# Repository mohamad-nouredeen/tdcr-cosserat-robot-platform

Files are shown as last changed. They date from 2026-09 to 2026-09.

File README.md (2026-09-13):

# Tendon-Driven Continuum Robot Platform

A single-segment tendon-driven continuum robot developed during my
master's thesis internship at ISIR, Sorbonne Université, as part of the
Master's Degree in Mechatronic Engineering at Politecnico di Torino.

This project integrates static and dynamic Cosserat-rod modeling,
mechanical design, DYNAMIXEL tendon actuation, electronics, and
preliminary experimental evaluation of a physical TDCR prototype.

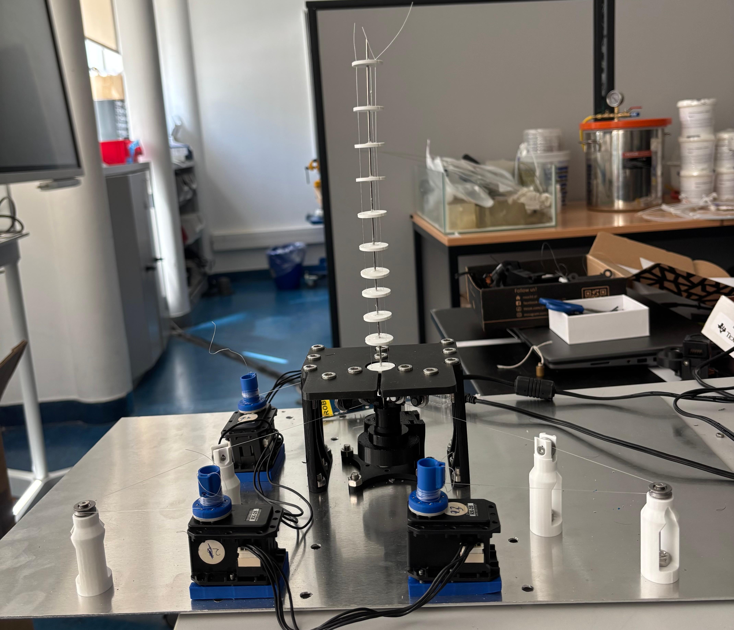
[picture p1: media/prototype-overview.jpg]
Complete tendon-driven continuum robot prototype


## Robot Demonstration

Physical prototype during tendon actuation.

https://github.com/user-attachments/assets/3df236bc-30ad-41d0-9584-1410d35f72d1

## Prototype

The developed robot consists of:

- A 250 mm hollow Nitinol backbone
- Eleven spacer disks
- Three nylon tendons arranged approximately 120° apart
- Three DYNAMIXEL RX-28 actuators
- Motor-driven tendon spools with a nominal effective radius of 2.5 mm
- A MATLAB R2025a actuation interface using the DYNAMIXEL SDK

The mathematical models use a nominal symmetric tendon-routing radius
of 6 mm. The supplied manufactured disk STL differs from this nominal
model geometry; the measured mesh geometry and related reproducibility
notes are documented in
[`mechanical/README.md`](mechanical/README.md).

## Modeling Approach

### Static Cosserat-Rod Models

Two static Cosserat-rod formulations are included.

**Newtonian formulation**

The Newtonian model is based on distributed force and moment equilibrium.
The spatial equations are integrated numerically using `ode45`, while a
shooting method and `fsolve` are used to satisfy the boundary conditions.

**Lagrangian formulation**

The Lagrangian model represents the rod strains through a finite
strain-basis approximation and determines the equilibrium configuration
using an energy-based formulation and Newton-Raphson iteration.

For the loading cases examined in the thesis, the two formulations
produced practically identical predicted tip positions.

The corresponding implementations are available in
[`modeling/`](modeling/).

### Displacement-to-Tension Iteration

The static Cosserat formulations use tendon tension as a model input,
while the physical actuation system is commanded using nominal tendon
pull.

An outer PD-based numerical iteration was therefore implemented to
adjust tendon tension until the Newtonian model reproduces a prescribed
tendon shortening.

This procedure is an offline numerical algorithm and is separate from
the physical DYNAMIXEL motor controller.

### Dynamic Model

The dynamic Cosserat-rod implementation investigates the transient
backbone response under time-dependent tendon tensions.

The formulation includes backbone inertia, internal damping, gravity,
drag, and time-dependent tendon loading. Temporal integration is based
on an implicit BDF-alpha formulation combined with spatial integration
of the rod equations.

The dynamic results contained in this repository are numerical
predictions and were not experimentally validated during the project.

## Actuation and Electronics

Three ROBOTIS DYNAMIXEL RX-28 actuators are used, with one actuator
assigned to each tendon.

The implemented communication architecture is:

```text
Computer / MATLAB R2025a
        |
       USB
        |
   ROBOTIS U2D2
        |
      RS-485
        |
   U2D2 Power Hub
        |
   RS-485 + Power
        |
      RX-28 ID 1
        |
    Daisy chain
        |
      RX-28 ID 2
        |
    Daisy chain
        |
      RX-28 ID 3
```

The MATLAB actuation interface converts prescribed nominal tendon pulls
into DYNAMIXEL Goal Position commands.

The motor shaft positions are internally regulated by the RX-28
controllers. However, actual tendon displacement, tendon tension,
backbone shape, and robot tip position are not directly measured.

The implementation is available in
[`actuation/`](actuation/), while the hardware architecture is
documented in [`electronics/`](electronics/).

## Preliminary Experimental Evaluation

The physical robot was compared with the Newtonian static model using
one unloaded condition and six single-active-tendon tests.

The nominal tendon-pull commands were 5 mm and 10 mm.

| Metric | Value |
|---|---:|
| Mean absolute vertical-position error | 11.54 mm |
| Root-mean-square vertical-position error | 14.01 mm |
| Maximum absolute vertical-position error | 21.08 mm |
| Mean relative error | Approximately 6.51% |

The model reproduced the principal relationship between increasing
nominal tendon pull and increasing backbone deformation.

However, the physical robot bent less than predicted by the static model,
particularly for the 10 mm commands.

Possible sources of discrepancy include tendon friction, slack,
elongation or permanent deformation, spool-winding effects,
manufacturing asymmetries, mechanical tolerances, and uncertainty
between commanded and actual tendon displacement.

The complete experimental comparison is documented in
[`experiments/`](experiments/).

## Repository Structure

| Location | Contents |
|---|---|
| [`modeling/`](modeling/) | Newtonian and Lagrangian static models, dynamic model, displacement-to-tension iteration, comparison scripts, and supporting MATLAB functions |
| [`actuation/`](actuation/) | MATLAB interface for commanding the DYNAMIXEL RX-28 actuators |
| [`mechanical/`](mechanical/) | Mechanical STL files and geometry/reproducibility documentation |
| [`electronics/`](electronics/) | Communication, power, U2D2, Power Hub, and actuator documentation |
| [`experiments/`](experiments/) | Experimental comparison figures, results, metrics, and discussion |
| [`docs/`](docs/) | Master's thesis and thesis documentation |
| [`media/`](media/) | Prototype photographs and robot demonstration video |
| [`CITATION.cff`](CITATION.cff) | Citation metadata for this repository |
| [`THIRD_PARTY_NOTICES.md`](THIRD_PARTY_NOTICES.md) | Attribution and third-party software information |
| [`LICENSE`](LICENSE) | GNU General Public License v3.0 |

## Master's Thesis

The complete thesis associated with this repository is:

**Static and Dynamic Cosserat-Rod Modeling of a Single-Segment
Tendon-Driven Continuum Robot**

**Author:** Mohamad Nour Edeen  
**Master's Degree:** Mechatronic Engineering  
**University:** Politecnico di Torino  
**Research host:** ISIR, Sorbonne Université

[Read the thesis PDF](docs/Master_Thesis_Mohamad_Nouredeen.pdf)

Additional thesis information is available in
[`docs/README.md`](docs/README.md).

## Software Requirements

The thesis implementations were developed using **MATLAB R2025a**.

The static Newtonian and dynamic implementations use `fsolve` from the
MATLAB Optimization Toolbox.

The physical actuation interface additionally requires the
ROBOTIS DYNAMIXEL SDK and compatible DYNAMIXEL hardware.

The repository version has not yet been independently reproduced on a
separate computer. Users should therefore verify dependencies,
environment configuration, and hardware settings before execution.

## Attribution

Parts of the static Newtonian and Lagrangian Cosserat-rod
implementations are adapted from the open-source TIMClab-CAMI project
associated with:

Matthias Tummers et al. (2023),  
**"Cosserat Rod Modeling of Continuum Robots from Newtonian and
Lagrangian Perspectives,"**  
*IEEE Transactions on Robotics*.

DOI:  
https://doi.org/10.1109/TRO.2023.3238171

Original implementation:  
https://github.com/TIMClab-CAMI/Cosserat-Rod-Modeling-of-Tendon-Actuated-Continuum-Robots

The project-specific adaptations include robot geometry and material
parameters, tendon-routing configuration, additional numerical outputs,
comparison procedures, and the displacement-to-tension iteration.

Detailed attribution information is provided in
[`THIRD_PARTY_NOTICES.md`](THIRD_PARTY_NOTICES.md).

The repository includes the applicable GPL-3.0 license text in
[`LICENSE`](LICENSE).

## Citation

If you use material from this repository, please cite the repository
using the metadata provided in:

[`CITATION.cff`](CITATION.cff)

Users of the adapted static Cosserat-rod implementation should also cite
the original Tummers et al. publication listed above.

## Author

**Mohamad Nour Edeen**

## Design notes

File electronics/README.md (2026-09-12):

# Electronics and Actuation Hardware

This folder documents the electronic, communication, and actuator architecture implemented for the tendon-driven continuum robot platform.

The system uses three ROBOTIS DYNAMIXEL RX-28 actuators, one for each tendon. MATLAB R2025a communicates with the actuators through a ROBOTIS U2D2 interface and a U2D2 Power Hub.

## System Architecture

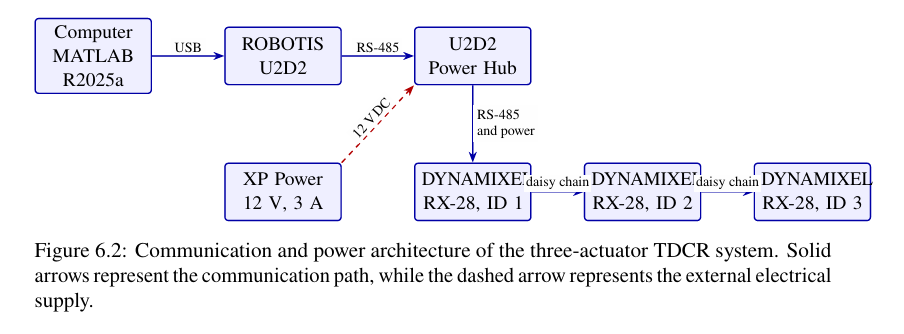
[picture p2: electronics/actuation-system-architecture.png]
Actuation system architecture


The implemented communication and power chain is:

```text
Computer / MATLAB R2025a
        |
       USB
        |
   ROBOTIS U2D2
        |
      RS-485
        |
   U2D2 Power Hub
        |
   RS-485 + Power
        |
 DYNAMIXEL RX-28, ID 1
        |
    Daisy chain
        |
 DYNAMIXEL RX-28, ID 2
        |
    Daisy chain
        |
 DYNAMIXEL RX-28, ID 3
 
 An external 12 V, 3 A power supply is connected to the U2D2 Power Hub, which distributes power and communication to the three actuators.

The motor assignments are:

| Motor ID | Function |
|---|---|
| ID 1 | Tendon 1 |
| ID 2 | Tendon 2 |
| ID 3 | Tendon 3 |

## ROBOTIS U2D2 Interface

![ROBOTIS U2D2 interface](u2d2-interface.png)

The U2D2 provides the communication interface between the computer and the DYNAMIXEL actuator network.

## U2D2 Power Hub

![U2D2 Power Hub](u2d2-power-hub.png)

The U2D2 Power Hub connects the communication interface, external power supply, and actuator network.

## DYNAMIXEL RX-28 Actuation Unit

![DYNAMIXEL RX-28 actuator unit](rx28-actuator-unit.png)

Three DYNAMIXEL RX-28 actuators are mounted on the mechanical base. Each actuator controls one tendon through the corresponding spool and transmission mechanism.

The actuators regulate their shaft position internally. However, the robot does not directly measure tendon tension, actual tendon displacement, backbone shape, or tip position.

## Motor Configuration

![DYNAMIXEL Wizard RX-28 configuration](dynamixel-wizard-rx28.png)

The actuators were configured and identified using ROBOTIS DYNAMIXEL Wizard 2.0. Unique motor IDs allow all three actuators to share the same communication bus while remaining independently addressable.

## MATLAB Actuation Interface

The corresponding MATLAB implementation is located in:

[`../actuation/TDCR_MotorPullCommand.m`](../actuation/TDCR_MotorPullCommand.m)

The script converts prescribed nominal tendon pulls into DYNAMIXEL Goal Position commands.

The nominal spool radius used in the implementation is 2.5 mm.

## System Limitations

The current platform does not directly measure:

- Actual tendon displacement
- Tendon tension
- Tendon elongation
- Backbone configuration
- Tip position

Therefore, friction, tendon slack, elongation, spool winding, and mechanical tolerances can cause differences between the nominal command and the actual robot motion.

## Related Documentation

See the [main project README](../README.md) for the complete project overview.

Mechanical components and STL files are documented in [`../mechanical/`](../mechanical/).

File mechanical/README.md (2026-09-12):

# Mechanical Design

This folder contains STL exports of mechanical components developed
for the tendon-driven continuum robot platform.

The files include the backbone disk, base structure, pulley supports,
tendon guides, actuator mounts, and coupling components.

## Files

The STL files are stored in [STL](STL/).
Original filenames have been preserved.

| File | Component description |
|---|---|
| `Disk_tendon.STL` | Disk identified by the author as used in the prototype |
| `BasePlatform.stl` | Base platform plate |
| `BasePlatform_wall.stl` | Base wall/support component |
| `BasePlatform_PullyHolder.stl` | Pulley holder |
| `BasePlatform_PulleyShaft.stl` | Pulley retaining shaft |
| `holder_tendon_horizontal.stl` | Horizontal tendon-guide support |
| `holder_tendon_vertical.stl` | Vertical tendon-guide support |
| `Tube_coppling_1mm.stl` | Backbone tube support/coupling |
| `ActuationUnit_EncoderCouplingSide.stl` | Encoder-side support component |
| `ActuationUnit_MotorSide_Cube.stl` | Motor-side support component |
| `Shaft_GearCoupling.stl` | Gear-coupling shaft component |
| `Shaft_MotorEncoder.stl` | Motor/encoder shaft component |
| `dynamixel/BASE1_DAYNAMIXEL.STL` | DYNAMIXEL mounting component |
| `dynamixel/Base_dynamixel.STL` | DYNAMIXEL mounting component |
| `dynamixel/coupling_connection.STL` | DYNAMIXEL coupling component |

Descriptions are based on filenames and geometry inspection.
Assembly positions and quantities remain to be documented.

The presence of motor, gear, and encoder components does not establish
an operational axial-rotation mechanism. Axial rotation was a proposed
future capability and was not actuated in the thesis experiments.

## Manufacturing

The thesis reports PETG 3D printing for the custom mechanical parts.

STL files do not encode units. The exports have been interpreted in
millimetres; check the imported scale before printing.

Print orientation, supports, tolerances, and assembly fit should be
checked for each component. Complete printing settings and a bill of
materials are not yet included.

## Disk geometry and model differences

`Disk_tendon.STL` is retained as supplied and identified by the author
as the disk used in the physical robot.

Inspection of this mesh, assuming millimetres, gives:

| Feature | STL geometry |
|---|---|
| Outside diameter | Approximately 20 mm |
| Thickness | Approximately 2 mm |
| Centre-to-tendon-hole distances | Approximately 7.00, 7.17, and 7.17 mm |
| Central backbone passage | Approximately 3 mm diameter |
| Tendon passages | Approximately 2.5 mm at the faces, narrowing to 1 mm internally |

These are mesh measurements, not measurements of the manufactured part.

The thesis and MATLAB models use a symmetric tendon-routing radius
of 6 mm. The thesis also describes a central disk passage tapering
from 3 mm to 1.5 mm. These differences remain unresolved and should
be considered when reproducing the model–prototype comparison.

The MATLAB parameters have been preserved to retain the reported
simulation configuration.

## Mesh inspection notes

The supplied exports have not been repaired:

- `Disk_tendon.STL` contains duplicate triangles and non-manifold edges.
- `ActuationUnit_MotorSide_Cube.stl` contains two non-manifold edges.
- `dynamixel/BASE1_DAYNAMIXEL.STL` contains small vertex seams that
  disappear when nearly coincident vertices are merged.

Inspect these meshes in CAD or slicing software before manufacturing.
Passing basic mesh checks does not establish dimensional accuracy
or assembly compatibility.

## Documentation status

This collection currently contains STL meshes. Editable CAD files,
assembly drawings, confirmed part quantities, and detailed assembly
instructions have not yet been added.

For the project overview, prototype photograph, and demonstration
video, see the [main README](../README.md).

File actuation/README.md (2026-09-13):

# DYNAMIXEL Tendon Actuation

This folder contains the MATLAB interface used to convert prescribed
nominal tendon pulls into DYNAMIXEL RX-28 Goal Position commands for the
three-tendon continuum robot.

The physical actuation system consists of three ROBOTIS DYNAMIXEL RX-28
actuators, one for each tendon.

## Main File

| File | Purpose |
|---|---|
| `TDCR_MotorPullCommand.m` | Converts nominal tendon-pull commands into DYNAMIXEL Goal Position commands and sends them to the three RX-28 actuators |

## Actuation Architecture

The high-level actuation sequence is:

```text
Nominal tendon pull [mm]
        |
        v
MATLAB R2025a
        |
        v
Convert tendon pull to spool rotation
        |
        v
Convert spool rotation to DYNAMIXEL Goal Position
        |
        v
ROBOTIS U2D2
        |
        v
U2D2 Power Hub
        |
        v
RX-28 actuators

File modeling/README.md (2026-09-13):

# Cosserat-Rod Modeling

This folder contains the MATLAB implementation of the static and dynamic
Cosserat-rod models used for the single-segment tendon-driven continuum
robot (TDCR).

The modeling work includes:

- Newtonian static Cosserat-rod formulation
- Lagrangian static Cosserat-rod formulation
- Numerical comparison of the two static formulations
- Displacement-to-tension iteration
- Dynamic Cosserat-rod formulation
- Supporting mathematical and numerical functions

The implementations were developed and evaluated using MATLAB R2025a.

## Main Files

| File | Purpose |
|---|---|
| `Newtonian.m` | Newtonian force-and-moment equilibrium formulation for static TDCR modeling |
| `Lagrangian.m` | Lagrangian energy-based formulation for static TDCR modeling |
| `Newtonian_PD.m` | Newtonian model used with the displacement-to-tension numerical iteration |
| `TDCR_DynamicModel.m` | Dynamic Cosserat-rod implementation |
| `compare_four_cases.m` | Numerical comparison of selected Newtonian and Lagrangian static cases |
| `main_Lagrangian.m` | Entry script for running the Lagrangian static formulation |
| `run_PD_test.m` | Demonstration of the displacement-to-tension iteration |
| `materials.m` | Backbone material and constitutive parameters |
| `tendons.m` | Tendon geometry and routing parameters |

## Supporting Functions

### `Lagrangian_approach_subfunctions/`

Contains mathematical and numerical functions required by the
Lagrangian formulation, including strain-basis, quaternion,
Lie-algebra, integration, and plotting utilities.

### `tools/`

Contains shared numerical and post-processing utilities used by the
static modeling workflow.

These include functions for:

- Rotation and quaternion operations
- Numerical integration
- Result reading and saving
- Tendon-tension combinations
- Static-model visualization and comparison

## Static Newtonian Formulation

The Newtonian formulation describes the backbone through Cosserat-rod
kinematics together with distributed force and moment equilibrium.

The spatial differential equations are integrated using MATLAB `ode45`.
Unknown boundary quantities are determined through a shooting method
using `fsolve`.

For a prescribed tendon-tension vector, the model predicts the complete
backbone configuration and the resulting tip pose.

## Static Lagrangian Formulation

The Lagrangian formulation represents the distributed rod strains using
a finite set of basis functions and generalized coordinates.

The equilibrium configuration is obtained from the energy-based
formulation through a Newton-Raphson numerical solution.

The Newtonian and Lagrangian formulations produced practically identical
tip positions for the loading cases investigated in the thesis.

## Static Model Comparison

The script

```matlab
compare_four_cases

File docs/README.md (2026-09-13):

# Thesis Documentation

This folder contains the final master's thesis associated with the
tendon-driven continuum robot platform developed at ISIR, Sorbonne
Université.

## Master's Thesis

**Title:**  
Static and Dynamic Cosserat-Rod Modeling of a Single-Segment
Tendon-Driven Continuum Robot

**Author:**  
Mohamad Nour Edeen

**Degree:**  
Master's Degree in Mechatronic Engineering

**University:**  
Politecnico di Torino

**Research host:**  
ISIR, Sorbonne Université

The complete thesis is available here:

[Master_Thesis_Mohamad_Nouredeen.pdf](Master_Thesis_Mohamad_Nouredeen.pdf)

## Thesis Overview

The thesis develops an integrated modeling and experimental framework
for a single-segment tendon-driven continuum robot (TDCR).

The work combines:

- Mechanical design and prototype development
- Static Cosserat-rod modeling
- Newtonian and Lagrangian formulations
- Numerical displacement-to-tension estimation
- Dynamic Cosserat-rod modeling
- DYNAMIXEL RX-28 tendon actuation
- MATLAB-based system integration
- Preliminary experimental evaluation

The work applies and adapts established Cosserat-rod formulations to
the geometry and physical parameters of the developed robot rather than
proposing a new fundamental rod theory.

## Thesis Structure

The thesis is organized into eight chapters.

### Chapter 1 — Introduction

Introduces the motivation, problem statement, objectives, scope,
methodology, and principal contributions of the work.

### Chapter 2 — Continuum Robotics: Background and State of the Art

Reviews continuum-robot architectures, tendon-driven continuum robot
design principles, backbone-modeling approaches, and relevant control
strategies.

### Chapter 3 — Design and Development of the TDCR Platform

Presents the mechanical design, SolidWorks development, material
selection, additive manufacturing, assembly, and final TDCR prototype.

### Chapter 4 — Static Modeling Based on Cosserat-Rod Theory

Develops and compares the Newtonian and Lagrangian static Cosserat-rod
formulations.

The chapter also presents the numerical displacement-to-tension
procedure used to relate prescribed tendon shortening to the tendon
loads required by the static model.

### Chapter 5 — Dynamic Modeling of the TDCR

Introduces the dynamic Cosserat-rod formulation and the numerical
simulation of the time-dependent backbone response under prescribed
tendon loading.

### Chapter 6 — Actuation and System Integration

Describes actuator selection, tendon transmission, DYNAMIXEL RX-28
communication, power and communication hardware, and the MATLAB-based
actuation interface.

### Chapter 7 — Experimental Evaluation and Discussion

Presents the preliminary single-active-tendon experimental evaluation
and compares the static Newtonian model with the physical prototype
under equivalent nominal tendon-pull commands.

The chapter also discusses the main causes of discrepancy between the
model and the experimental robot.

### Chapter 8 — Conclusions and Future Work

Summarizes the principal outcomes and limitations of the project and
discusses future developments including parameter calibration, sensing,
dynamic experimental validation, and closed-loop control.

## Repository Relationship

The thesis provides the complete scientific and engineering description
of the project. The corresponding implementation files are organized
throughout this repository.

- [`../modeling/`](../modeling/)  
  Static Newtonian and Lagrangian models, dynamic model,
  displacement-to-tension procedure, and supporting MATLAB functions.

- [`../actuation/`](../actuation/)  
  MATLAB interface for commanding the DYNAMIXEL RX-28 actuators.

- [`../mechanical/`](../mechanical/)  
  Mechanical-component documentation and STL files.

- [`../electronics/`](../electronics/)  
  Communication, power, and actuator hardware architecture.

- [`../experiments/`](../experiments/)  
  Preliminary experimental comparison, measurements, figures, and
  validation results.

- [`../media/`](../media/)  
  Prototype photographs and demonstration media.

## Important Reproducibility Note

The repository contains the implementation and design files associated
with the thesis, but the physical prototype includes manufacturing,
assembly, transmission, and material effects that are not fully
represented by the mathematical models.

In particular, tendon friction, slack, elongation, spool winding,
manufacturing tolerances, and uncertainty in actual tendon displacement
can influence the physical robot response.

The experimental comparison should therefore be interpreted as a
preliminary evaluation of the model–prototype relationship rather than
a complete calibrated validation of the system.

## Project Overview

For a concise introduction to the complete project, see the
[main repository README](../README.md).

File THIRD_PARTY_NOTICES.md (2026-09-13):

# Third-Party Notices

This repository contains original project material together with portions of MATLAB code adapted from previously published open-source research.

## TIMClab-CAMI Cosserat-Rod Modeling Code

Parts of the static Newtonian and Lagrangian Cosserat-rod implementations in the `modeling/` directory are adapted from the open-source project:

**Cosserat Rod Modeling of Tendon-Actuated Continuum Robots**

Original repository:  
https://github.com/TIMClab-CAMI/Cosserat-Rod-Modeling-of-Tendon-Actuated-Continuum-Robots

Associated publication:

Matthias Tummers et al.,  
*"Cosserat Rod Modeling of Continuum Robots from Newtonian and Lagrangian Perspectives,"*  
IEEE Transactions on Robotics, 2023.

DOI:  
https://doi.org/10.1109/TRO.2023.3238171

The original software is distributed under the **GNU General Public License version 3 (GPL-3.0)**.

The GPL-3.0 license text is included in the repository root as [`LICENSE`](LICENSE).

## Modifications in This Repository

The static modeling implementation was adapted for the tendon-driven continuum robot developed in this project.

Project-specific modifications include, where applicable:

- Adaptation of the robot geometry and backbone parameters
- Adaptation of material properties for the hollow Nitinol backbone
- Adaptation of the tendon-routing configuration
- Addition of project-specific simulation inputs and outputs
- Addition of comparison scripts
- Addition of the numerical displacement-to-tension procedure
- Integration with the broader TDCR modeling and experimental workflow

The modified files should not be interpreted as the original unmodified TIMClab-CAMI implementation.

## Other Project Material

The mechanical designs, experimental documentation, electronics documentation, prototype media, MATLAB actuation interface, thesis documentation, and project-specific integration presented in this repository were developed as part of the associated master's thesis project unless otherwise indicated within individual files.

## Citation

Users of the adapted Cosserat-rod implementation should cite the original Tummers et al. publication in addition to this repository.

Citation information for this repository is available in [`CITATION.cff`](CITATION.cff).

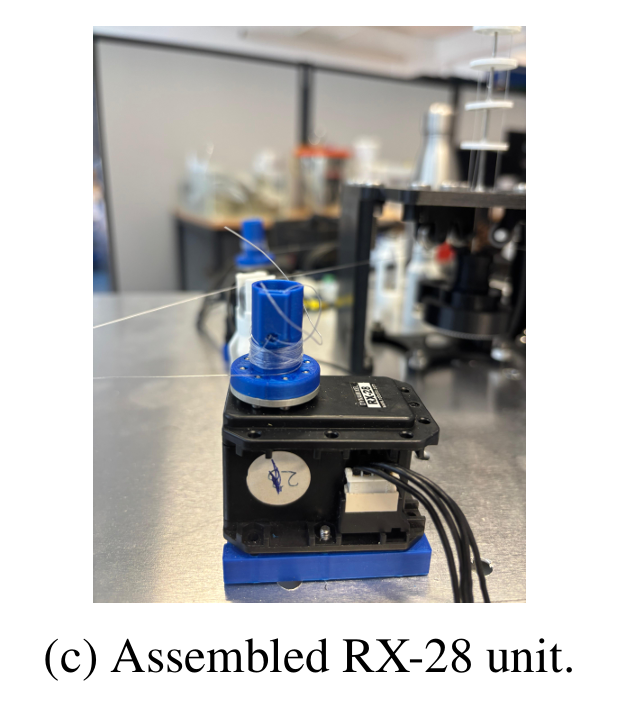
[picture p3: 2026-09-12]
electronics/rx28-actuator-unit.png

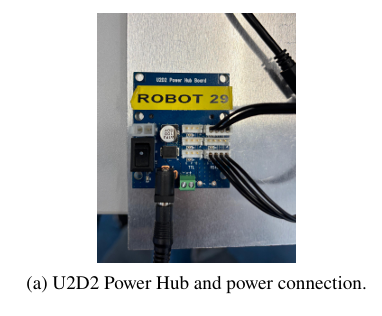
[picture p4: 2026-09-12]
electronics/u2d2-power-hub.png

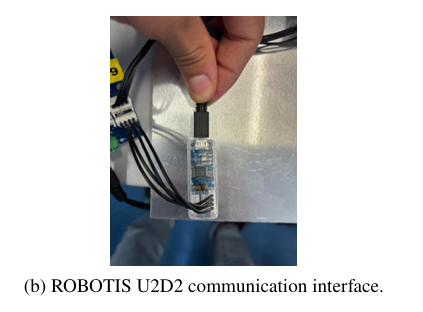
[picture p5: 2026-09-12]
electronics/u2d2-interface.png

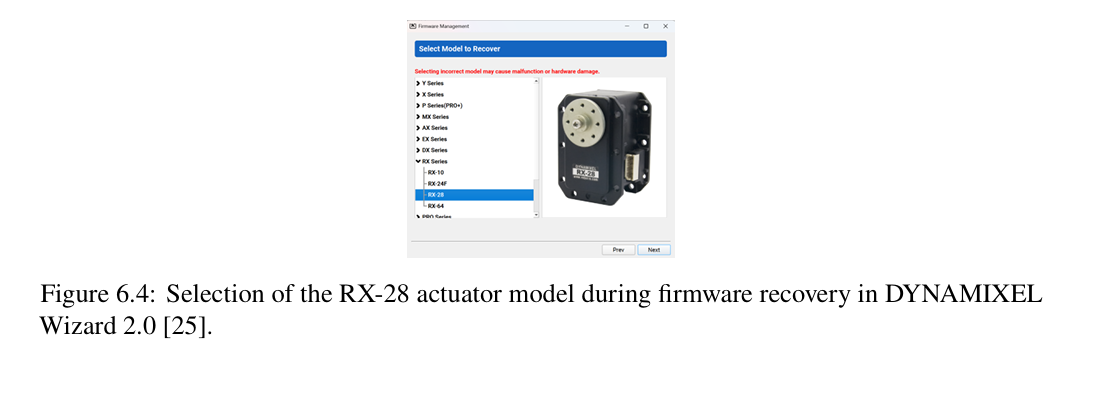
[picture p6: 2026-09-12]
electronics/dynamixel-wizard-rx28.png

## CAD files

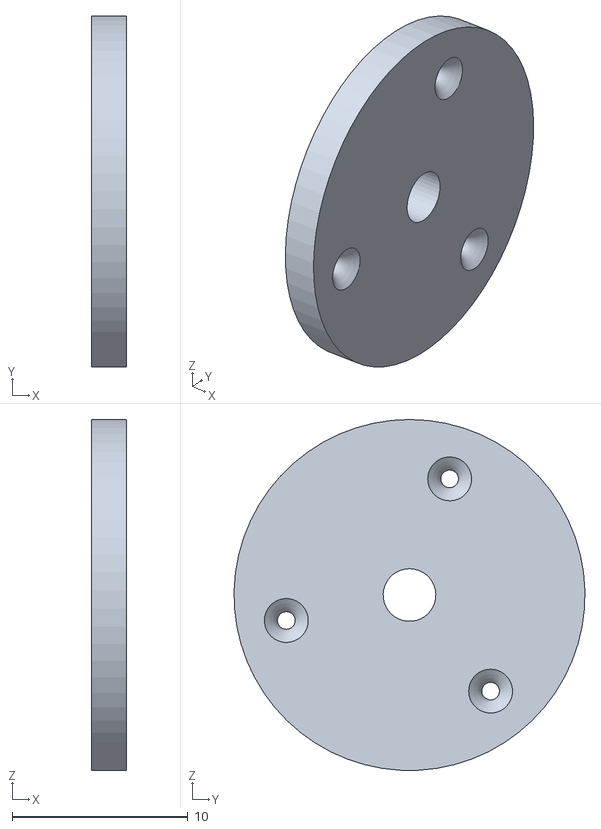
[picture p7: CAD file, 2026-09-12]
mechanical/STL/Disk_tendon.STL
2.00 x 20.0 x 20.0

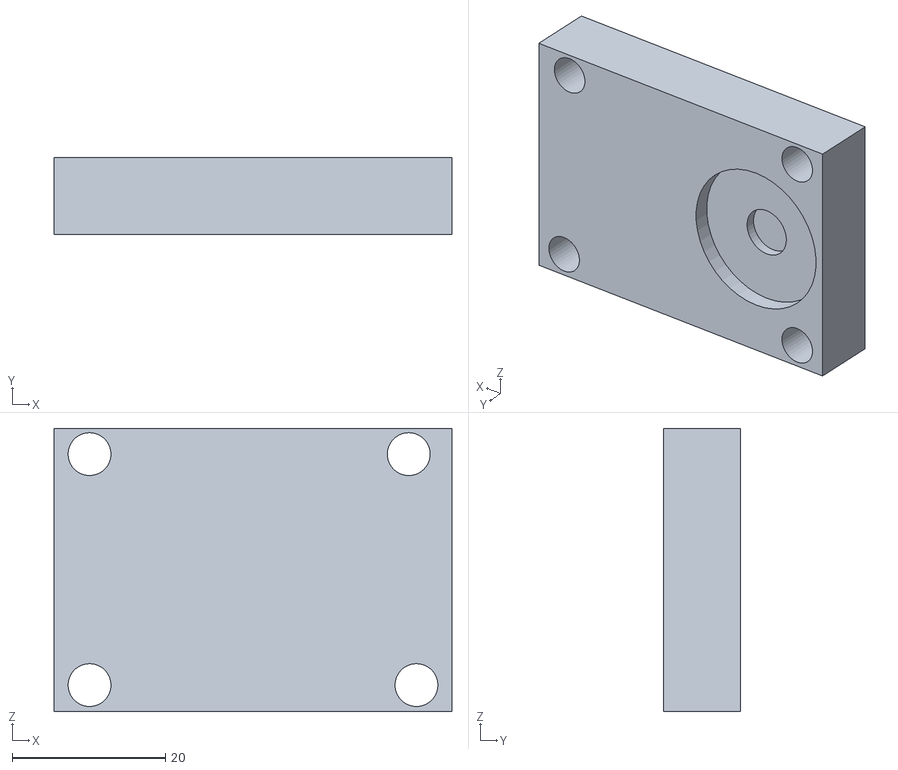
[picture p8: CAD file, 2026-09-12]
mechanical/STL/dynamixel/Base_dynamixel.STL
52.0 x 10.0 x 37.0

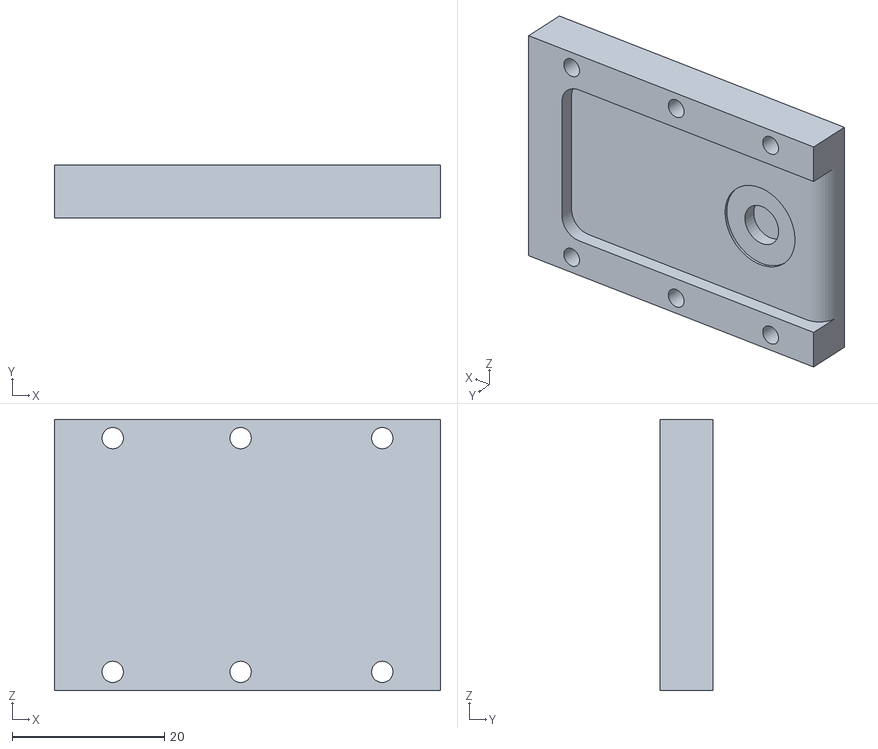
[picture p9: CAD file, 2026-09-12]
mechanical/STL/dynamixel/BASE1_DAYNAMIXEL.STL
50.7 x 7.00 x 35.6

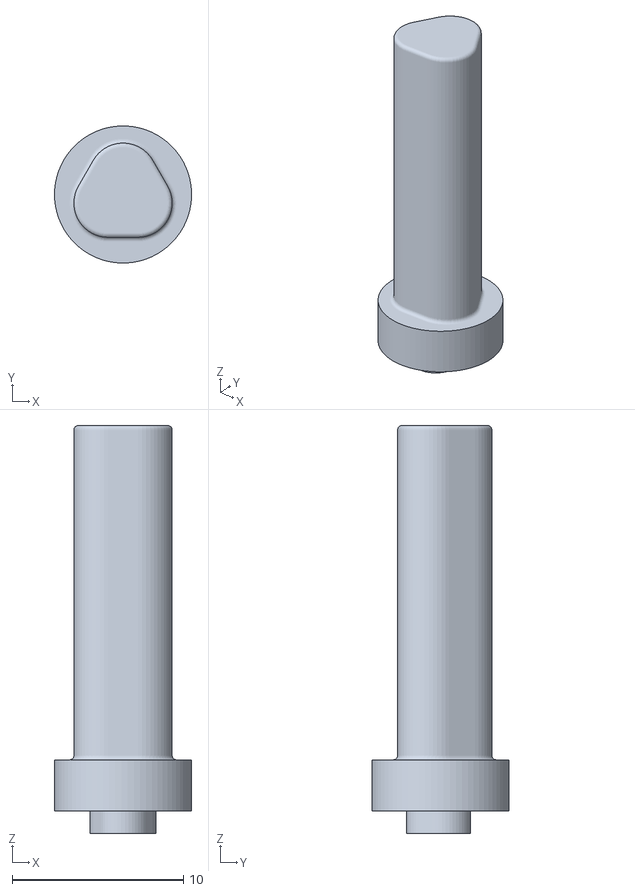
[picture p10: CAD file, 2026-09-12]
mechanical/STL/Shaft_MotorEncoder.stl
8.00 x 8.00 x 23.8

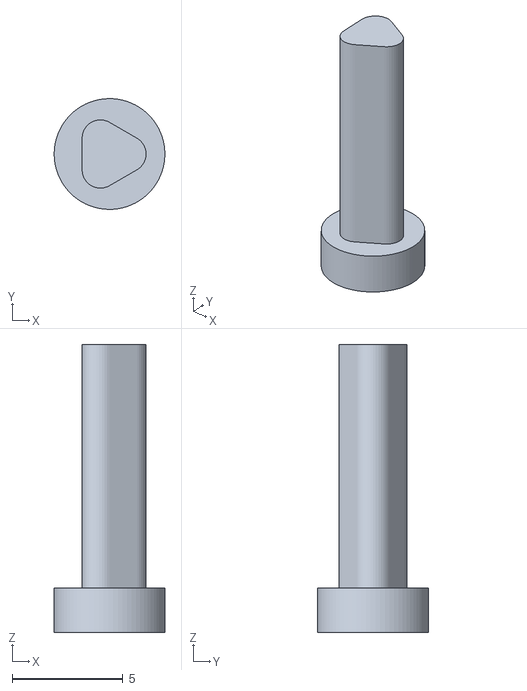
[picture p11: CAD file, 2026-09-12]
mechanical/STL/BasePlatform_PulleyShaft.stl
5.00 x 5.00 x 13.0

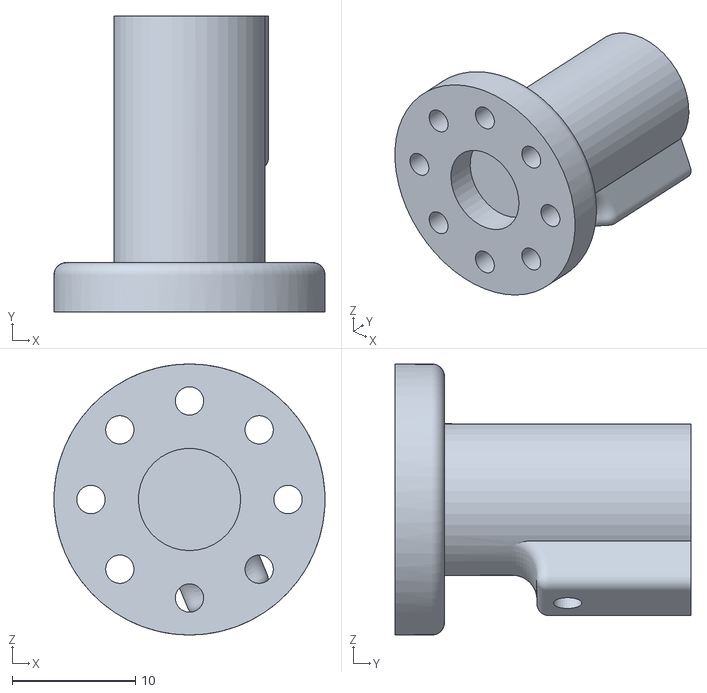
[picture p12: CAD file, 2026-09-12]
mechanical/STL/dynamixel/coupling_connection.STL
22.0 x 24.0 x 22.0

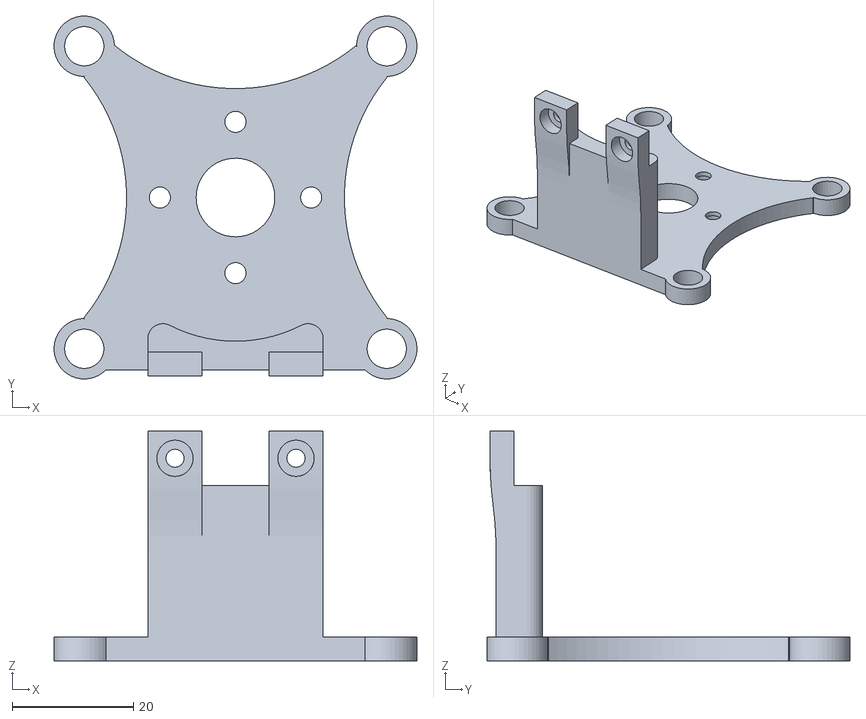
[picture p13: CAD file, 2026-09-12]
mechanical/STL/ActuationUnit_MotorSide_Cube.stl
60.0 x 60.0 x 38.0

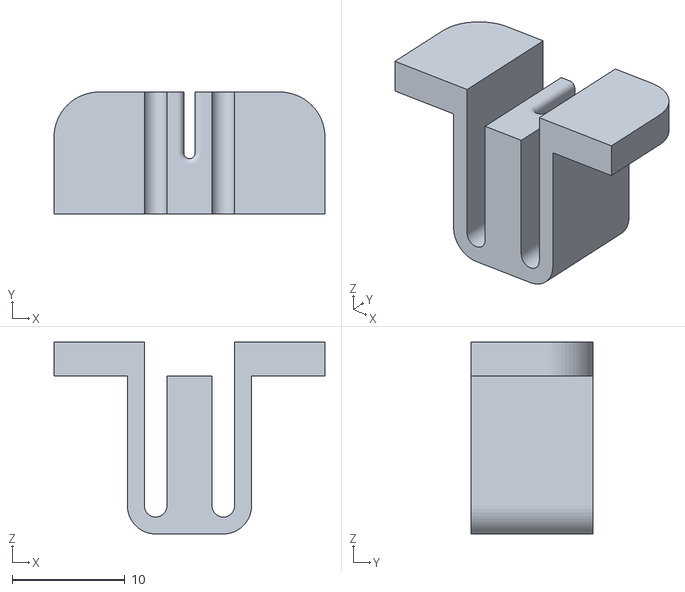
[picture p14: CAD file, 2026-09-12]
mechanical/STL/Tube_coppling_1mm.stl
24.0 x 10.8 x 17.0

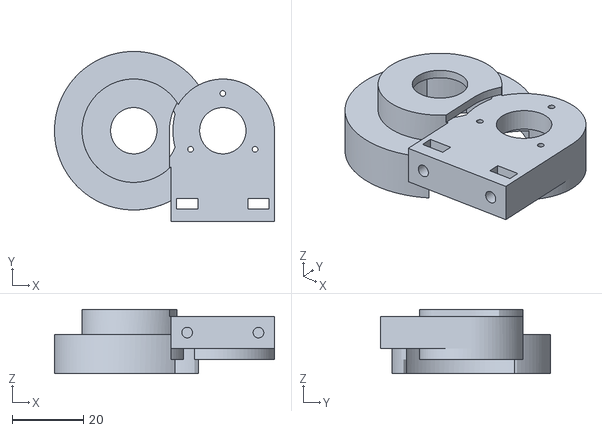
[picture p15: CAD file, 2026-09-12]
mechanical/STL/ActuationUnit_EncoderCouplingSide.stl
61.7 x 47.7 x 18.0

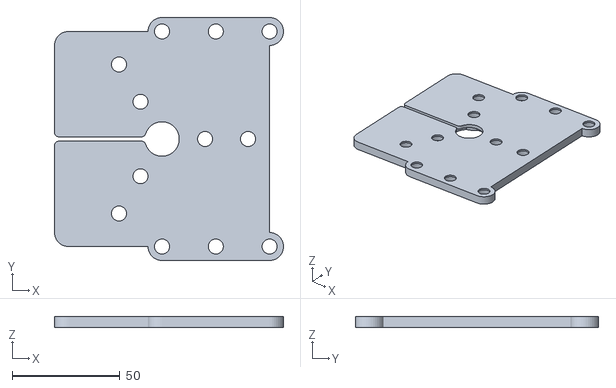
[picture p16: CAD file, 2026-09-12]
mechanical/STL/BasePlatform.stl
106.5 x 113.0 x 5.00

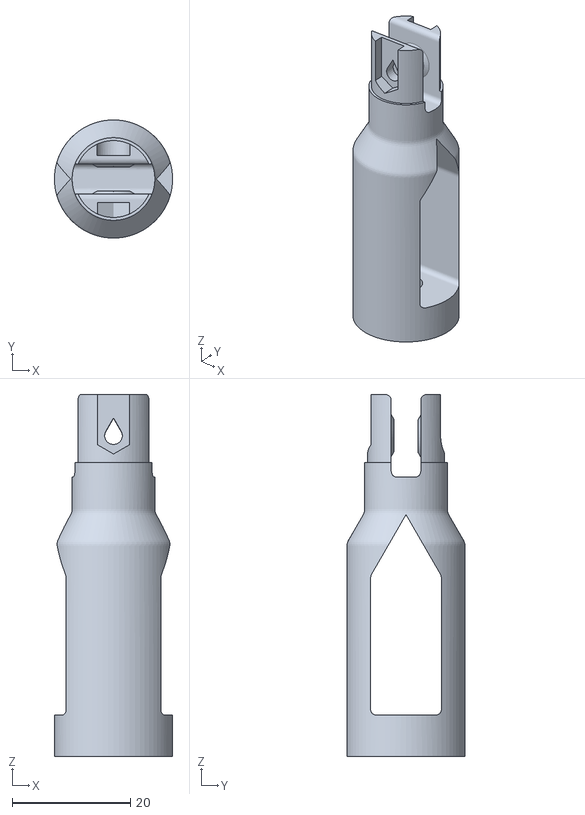
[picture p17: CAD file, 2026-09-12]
mechanical/STL/holder_tendon_vertical.stl
20.0 x 20.0 x 61.2

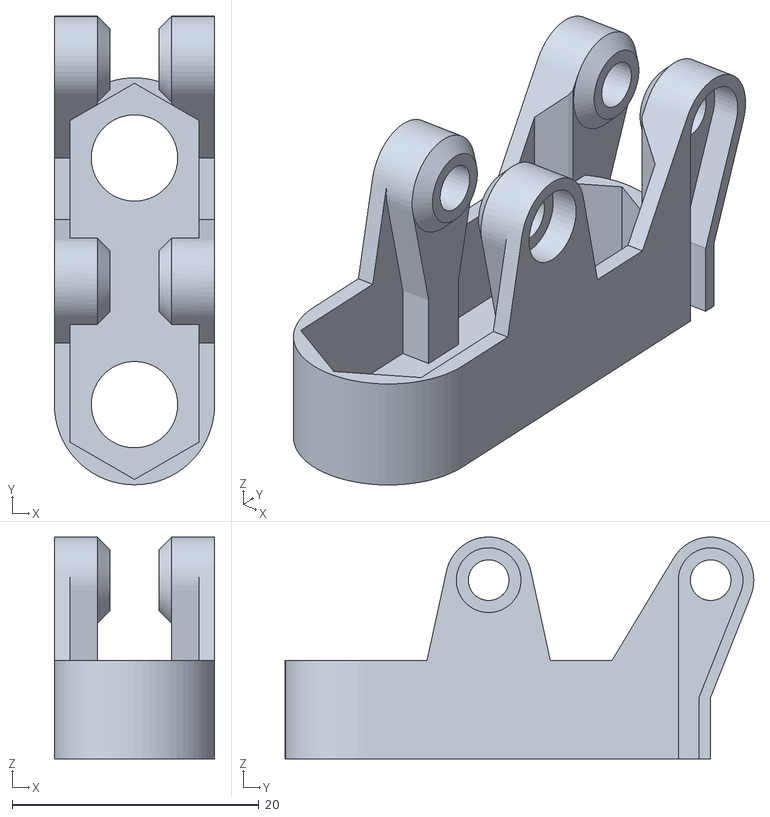
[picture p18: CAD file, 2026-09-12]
mechanical/STL/BasePlatform_PullyHolder.stl
13.0 x 38.0 x 18.0

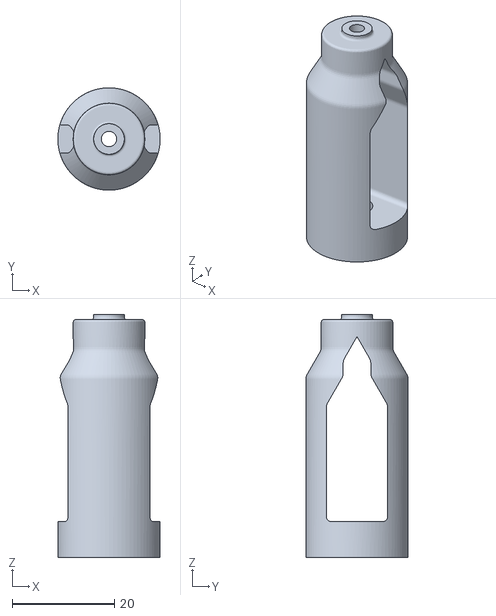
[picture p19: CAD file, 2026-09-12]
mechanical/STL/holder_tendon_horizontal.stl
20.0 x 20.0 x 47.5

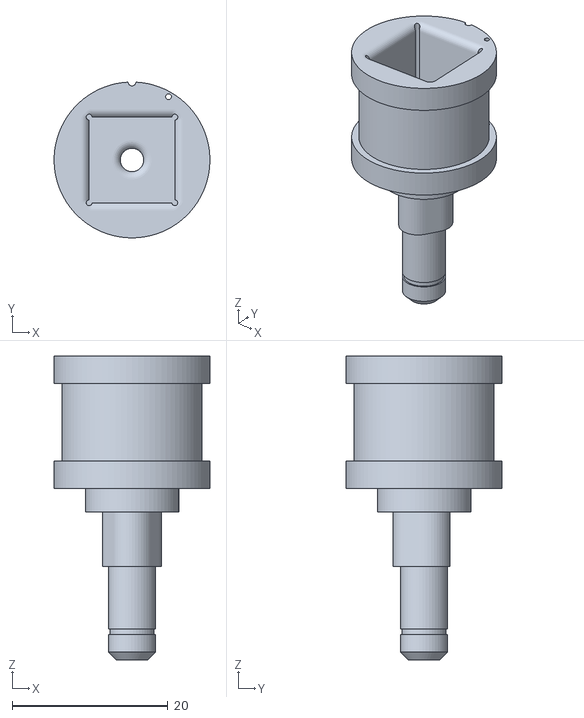
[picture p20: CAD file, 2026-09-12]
mechanical/STL/Shaft_GearCoupling.stl
20.0 x 20.0 x 39.0

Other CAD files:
mechanical/STL/BasePlatform_wall.stl

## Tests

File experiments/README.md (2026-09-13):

# Experimental Validation

This folder documents the preliminary experimental validation of the
single-segment tendon-driven continuum robot (TDCR).

The experimental tests compare the physical prototype with predictions
obtained from the Newtonian static Cosserat-rod model under equivalent
nominal tendon-pull commands.

## Validation Objective

The objective of the experiments was to evaluate whether the static
Cosserat-rod model reproduces the principal bending behavior of the
physical TDCR.

The comparison focused on the vertical coordinate of the robot tip,
\(z_{\mathrm{tip}}\), under single-active-tendon commands.

The validation should be considered preliminary because the experimental
setup did not directly measure tendon displacement, tendon tension, or the
complete three-dimensional backbone configuration.

## Test Cases

Seven operating conditions were evaluated:

| Test | Nominal tendon pull [mm] |
|---|---|
| Unloaded | [0, 0, 0] |
| Tendon 1 | [5, 0, 0] |
| Tendon 1 | [10, 0, 0] |
| Tendon 2 | [0, 5, 0] |
| Tendon 2 | [0, 10, 0] |
| Tendon 3 | [0, 0, 5] |
| Tendon 3 | [0, 0, 10] |

Only one tendon was actively commanded during each loaded test.

## Simulation and Experimental Results

The measured vertical tip coordinates were compared with the values
predicted by the Newtonian static model.

| Nominal tendon pull [mm] | Simulation z-tip [mm] | Experiment z-tip [mm] | Absolute error [mm] |
|---|---:|---:|---:|
| [0, 0, 0] | 250.00 | 250 | 0.00 |
| [5, 0, 0] | 230.01 | 233 | 2.99 |
| [10, 0, 0] | 149.92 | 171 | 21.08 |
| [0, 5, 0] | 230.01 | 235 | 4.99 |
| [0, 10, 0] | 149.92 | 168 | 18.08 |
| [0, 0, 5] | 230.01 | 233 | 2.99 |
| [0, 0, 10] | 149.92 | 169 | 19.08 |

Across the six loaded cases:

| Metric | Value |
|---|---:|
| Mean absolute error | 11.54 mm |
| Root-mean-square error | 14.01 mm |
| Maximum absolute error | 21.08 mm |
| Mean relative error | Approximately 6.51% |

The largest absolute error occurred for the `[10, 0, 0]` mm command.

## 5 mm Tendon-Pull Comparison

### Simulation

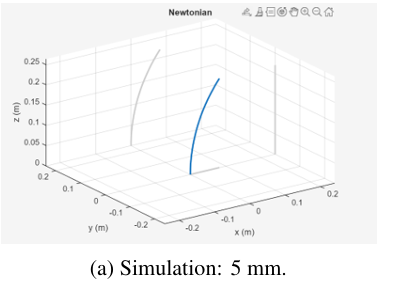
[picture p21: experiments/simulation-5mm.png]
Static simulation for 5 mm tendon pull


### Experiment

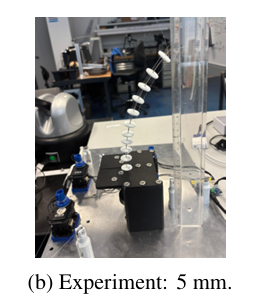
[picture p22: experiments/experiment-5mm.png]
Experimental configuration for 5 mm tendon pull


For the 5 mm single-tendon commands, the experimental vertical tip
coordinates remained relatively close to the model predictions.

The measured values were 233 mm, 235 mm, and 233 mm for Tendons 1, 2,
and 3, respectively, compared with a predicted value of approximately
230.01 mm.

## 10 mm Tendon-Pull Comparison

### Simulation

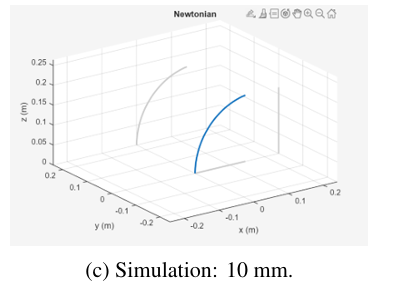
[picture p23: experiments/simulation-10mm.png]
Static simulation for 10 mm tendon pull


### Experiment

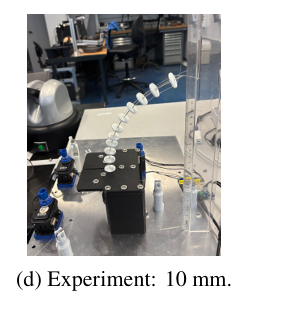
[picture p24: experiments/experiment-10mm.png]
Experimental configuration for 10 mm tendon pull


The discrepancy increased for the 10 mm commands.

The static model predicted a vertical tip coordinate of approximately
149.92 mm, while the experimental measurements were 171 mm, 168 mm,
and 169 mm for Tendons 1, 2, and 3, respectively.

The physical robot therefore bent less than predicted by the static
model at the larger nominal tendon pulls.

## Original Thesis Results Table

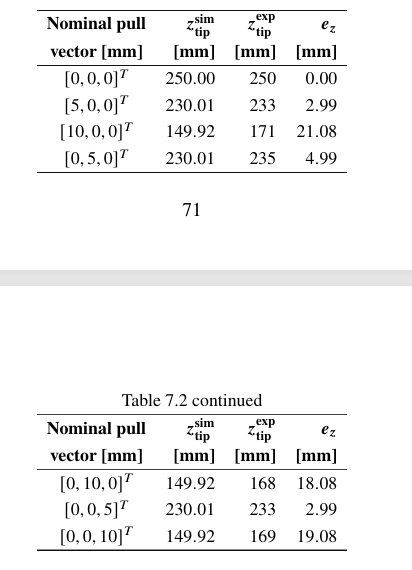
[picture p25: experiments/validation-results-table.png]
Experimental validation results table


The figure above reproduces the validation table reported in the thesis.
The numerical values are also provided directly in this README for
clarity and accessibility.

## Discussion

The experimental results reproduce the main qualitative trend predicted
by the model: increasing the nominal tendon pull produces greater
backbone deformation.

The results also show reasonable symmetry between the three tendon
directions. For the 5 mm commands, the measured vertical coordinates
were 233 mm, 235 mm, and 233 mm. For the 10 mm commands, they were
171 mm, 168 mm, and 169 mm.

However, the physical prototype consistently bent less than predicted
by the static model in the loaded cases, with the discrepancy becoming
more significant at the 10 mm commands.

Several effects can contribute to this difference:

- Tendon friction
- Tendon slack
- Tendon elongation and possible permanent deformation
- Spool-winding effects
- Mechanical tolerances
- Manufacturing asymmetries
- Uncertainty between commanded and actual tendon displacement
- Unmodeled transmission effects

Some of these effects are not represented in the static model.

## Experimental Limitations

The validation has several important limitations:

- Tendon tension was not directly measured.
- Actual tendon displacement was not directly measured.
- The complete backbone shape was not measured quantitatively.
- Only the vertical tip coordinate was used for the numerical comparison.
- Measurements were obtained manually.
- One measurement was available for each operating point.
- No statistical repeatability analysis was performed.

The reported results should therefore be interpreted as preliminary
experimental validation rather than a complete quantitative
identification of the robot model.

## Related Files

The static and dynamic Cosserat-rod implementations are available in:

[`../modeling/`](../modeling/)

The DYNAMIXEL motor command implementation is available in:

[`../actuation/`](../actuation/)

The electronic and actuator architecture is documented in:

[`../electronics/`](../electronics/)

The mechanical components and STL files are documented in:

[`../mechanical/`](../mechanical/)

For the complete project overview, see the
[main project README](../README.md).

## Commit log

2026-09-12 Add MATLAB models and tendon actuation scripts
2026-09-12 Display prototype photo in README
2026-09-12 Add mechanical STL files and documentation
    [ActuationUnit_EncoderCouplingSide.stl, ActuationUnit_MotorSide_Cube.stl, BASE1_DAYNAMIXEL.STL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]
